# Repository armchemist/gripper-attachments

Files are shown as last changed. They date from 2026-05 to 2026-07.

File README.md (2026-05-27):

# OMX-F 그리퍼 어태치먼트

OMX-F 로봇 팔 그리퍼에 끼워 쓰는 3D 프린팅 부품들 모음이다.

## 파일 구성

```
gripper-attachments/
├── GRIPPER_DIMENSIONS.md       핑거 치수 측정값 정리본
├── analyze_gripper.py          STL에서 단면 치수 뽑는 스크립트
├── gripper_sleeve.scad         범용 슬리브 (파라미터 조절용)
├── omx_f_gripper_sleeve.scad   OMX-F 핑거에 맞게 튜닝된 슬리브
├── omx_f_tube_insert.scad      시험관 잡는 팁 인서트
├── omx_f_tube_insert2~5.scad   튜브 인서트 개선 버전들
└── model/
    └── omx_f_mesh/
        └── follower_07_gripper_motorized.stl   원본 그리퍼 핑거 STL
```

## 새 부품 설계할 때

STL 파일 직접 열어서 치수 잴 필요 없이, `GRIPPER_DIMENSIONS.md`에 블레이드 단면 치수, 피벗 위치, 방향 기준이 다 정리되어 있다. 새 어태치먼트 만들 때는 여기 수치부터 보면 된다.

설계 전에 알아두면 좋은 것:

- **X 0~22 mm** 구간은 모터/기어 하우징이라 건드리면 안 된다
- **X 22~65 mm** 블레이드 구간이 부품 붙이는 영역
- 벽 두께 1.8 mm, 클리어런스 0.3 mm 정도가 FDM 출력 기준점

## OpenSCAD에서 끼움새 확인하는 법

`.scad` 파일 열면 위쪽에 `show_phantom` 파라미터가 있는데, `true`로 바꾸면 핑거 블레이드 형태가 반투명하게 같이 뜬다. 부품이 어디에 걸리는지 대충 보기엔 충분하다.

더 정확하게 원본 메시 위에 얹어서 보고 싶으면 파일 맨 아래에 이거 한 줄 추가하면 된다:

```scad
// 내보내기 전에 꼭 지울 것
%import("model/omx_f_mesh/follower_07_gripper_motorized.stl");
```

`%`를 붙이면 F5 프리뷰에서는 반투명 고스트로 보이고, F6 렌더링이나 STL 내보내기에는 포함이 안 된다. 출력 파일 걱정 없이 끼움새만 눈으로 확인할 수 있다.

## 출력 워크플로우

1. OpenSCAD에서 `.scad` 파일 열기
2. `show_phantom = true` 또는 `%import(...)` 추가하고 **F5**로 끼움새 확인
3. STL 내보낼 때는 다시 `false`로 돌리고 `%import` 줄 지우기
4. **F6** 렌더 → **F7** STL 내보내기
5. 출력 방향: X축이 베드 길이 방향이 되도록 눕혀서
6. 재료: PETG나 TPU 95A 추천, 벽 3~4겹, 인필 20%

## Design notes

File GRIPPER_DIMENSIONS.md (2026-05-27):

# OMX_F gripper finger dimensions

Source: STL analysis of `omx_f_mesh/follower_07_gripper_motorized.stl` (link6) and `follower_08_gripper_gear.stl` (link7), cross-referenced with `omx_f.urdf`. All units mm.

Reference these numbers when designing any gripper attachment (sleeve, jig, sensor mount, swap tool) instead of re-analyzing STLs.

## Mounting (from URDF, relative to link5)
- link6 pivot: xyz = (29.5, 7.5, 0), axis Z, mimic master
- link7 pivot: xyz = (29.5, -10.8, 0), axis Z, mimic of link6 ×(-1)
- Pivot Y spacing: 18.3 mm
- Both fingers symmetric (mirror in Y); link6 has motor housing, link7 has gear.

## Finger geometry (finger-local frame, X = length, pivot at X=0)
Total bbox: ~75 × 20 × ~42 mm (X × Y × Z, watertight).

| Zone | X range (mm) | Y width | Z height | Notes |
|---|---|---|---|---|
| Pivot shaft | -10 to 0 | ~0 (axle) | ~4 | rotation axis (Z) |
| Housing block | 0 to ~22 | ~20 | ~42 | motor/gear body — DO NOT cover |
| Grip blade (taper) | 22 to 65 | 11 → 7 | 39 → 16 | usable for attachments |
| Tip | 65 | <4 | ~15 | flat edge |

### Blade cross-sections (link6, symmetrized half-extents)
Measured via `trimesh.section()` (proper planar cross-section).
| Finger-local X | half_Y | half_Z |
|---|---|---|
| 22 (blade base) | 5.7  | 19.4 |
| 28 | 4.2  | 17.7 |
| 36 | 3.1  | 15.5 |
| 46 | 2.8  | 12.7 |
| 55 | 3.5  | 10.3 |
| 62 | 3.5  | 8.3  |
| 65 (tip) | ~3.0 | ~7.6 |

## Inner / outer face convention
- link6 "inner" (gripping) face = local **−Y** (faces partner finger at link7).
- link7 "inner" face = local **+Y** (mirror of link6).
- Closing direction at zero rotation: along link5's Y axis.

## Joint limits (URDF)
All revolute, effort 1000, velocity 4.8 rad/s, range ±2π:
joint1 (base yaw, Z), joint2/3/4 (pitch, Y), joint5 (roll, X), gripper_joint_1/2 (Z, mimic).

## Related files
- `analyze_gripper.py` — STL analysis script (re-run from this folder)
- `gripper_sleeve.scad` — parameterized slide-on sleeve (covers blade x=22..65)
- `../omx_f.urdf` — robot model
- `../omx_f_mesh/follower_07_*.stl`, `follower_08_*.stl` — finger meshes

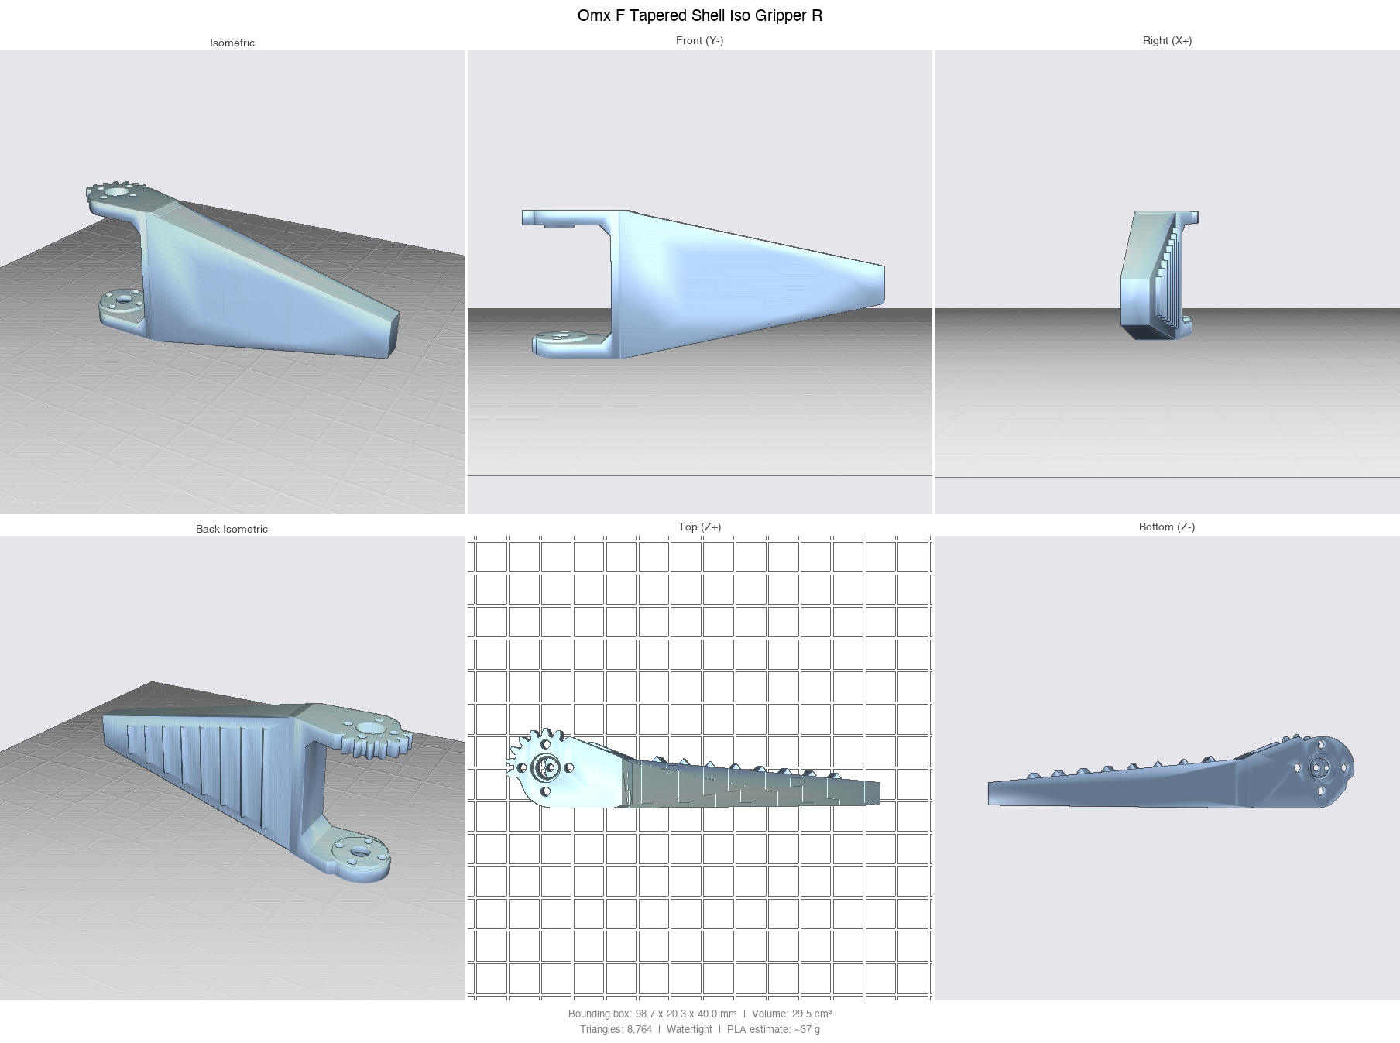
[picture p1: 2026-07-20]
gripper_designs/preview_iso_R.png

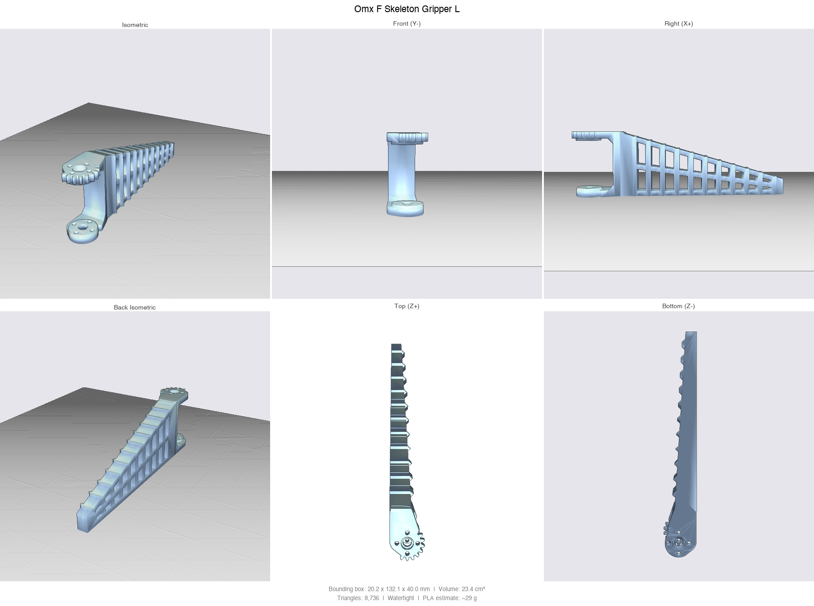
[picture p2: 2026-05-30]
gripper_designs/preview_skeleton.png

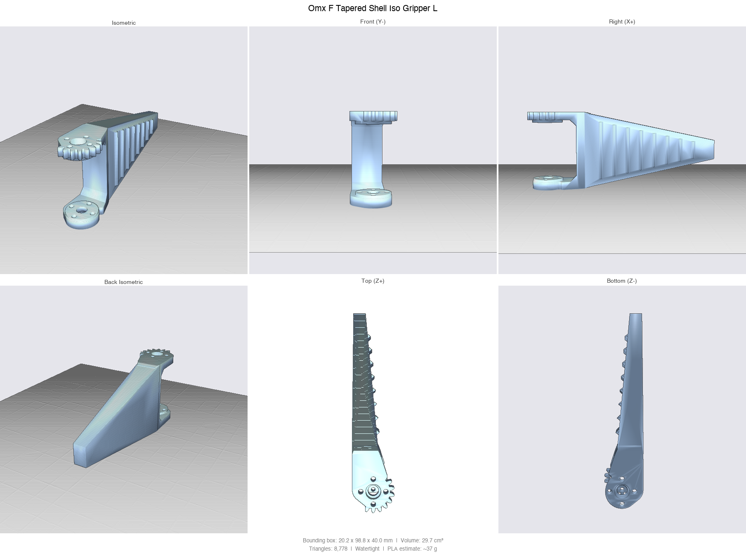
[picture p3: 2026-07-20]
gripper_designs/preview_iso.png

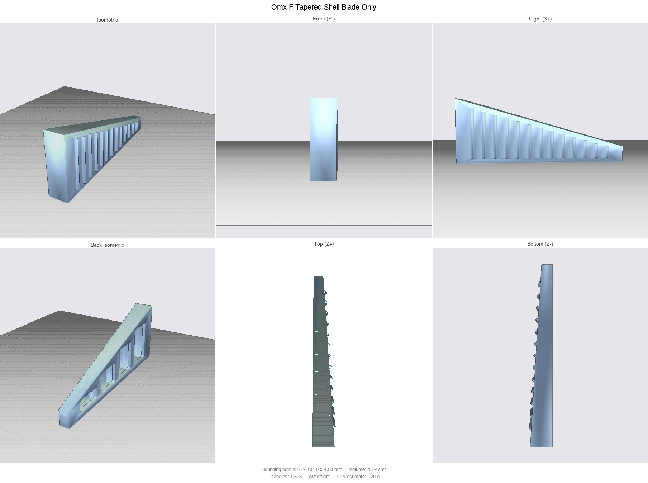
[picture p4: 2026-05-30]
gripper_designs/preview_blade.png

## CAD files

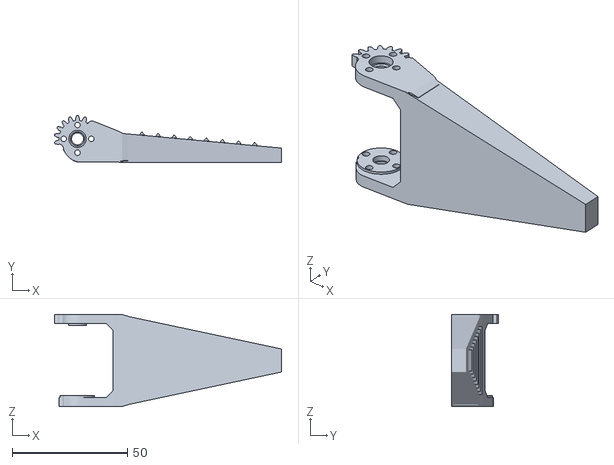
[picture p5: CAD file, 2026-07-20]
gripper_designs/omx_f_tapered_shell_iso_gripper_R.stl
98.7 x 20.3 x 40.0

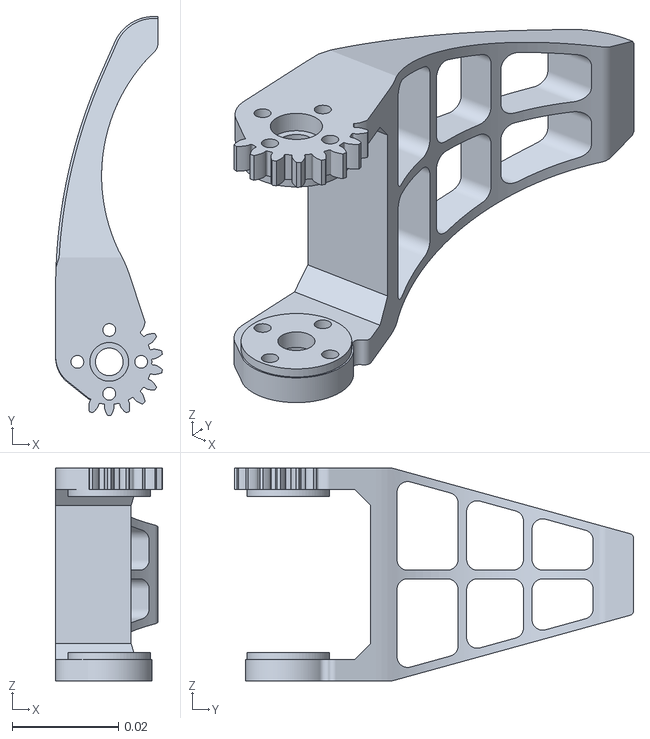
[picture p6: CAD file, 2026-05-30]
model/omx_f_mesh/follower_gripper_l.stl
0.0201 x 0.0751 x 0.04

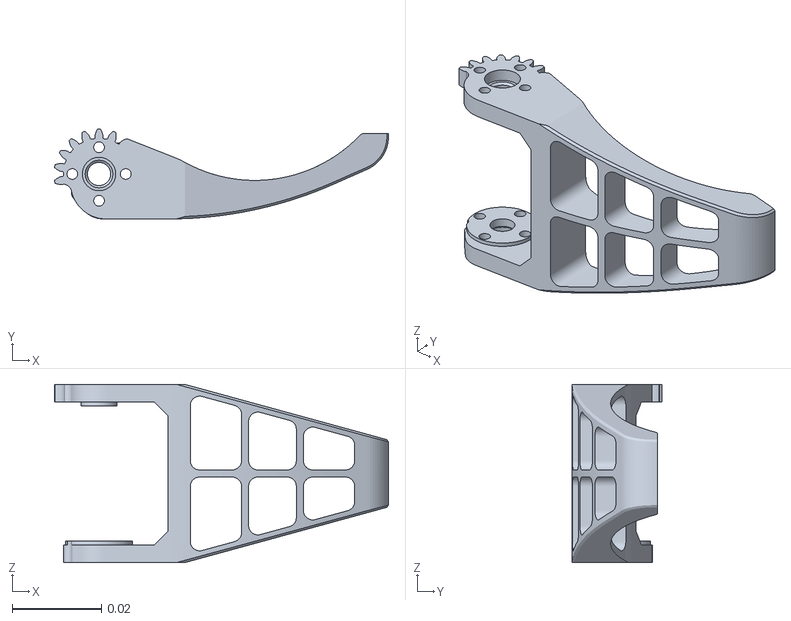
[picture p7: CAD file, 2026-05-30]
model/omx_f_mesh/follower_gripper_r.stl
0.075 x 0.0202 x 0.04

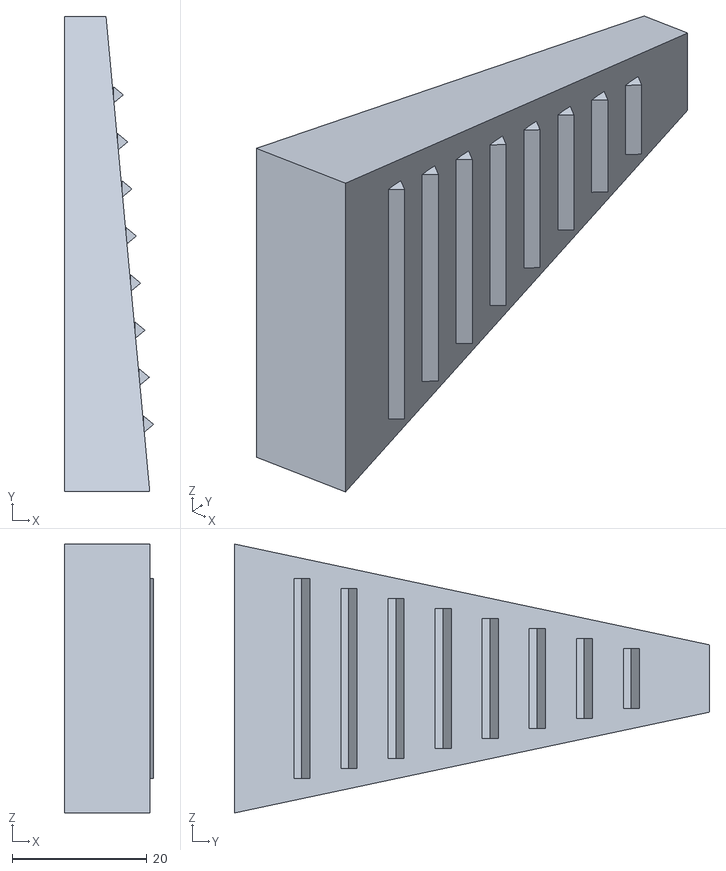
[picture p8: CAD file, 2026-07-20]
gripper_designs/omx_f_tapered_shell_iso_blade_only.stl
13.3 x 70.7 x 40.0

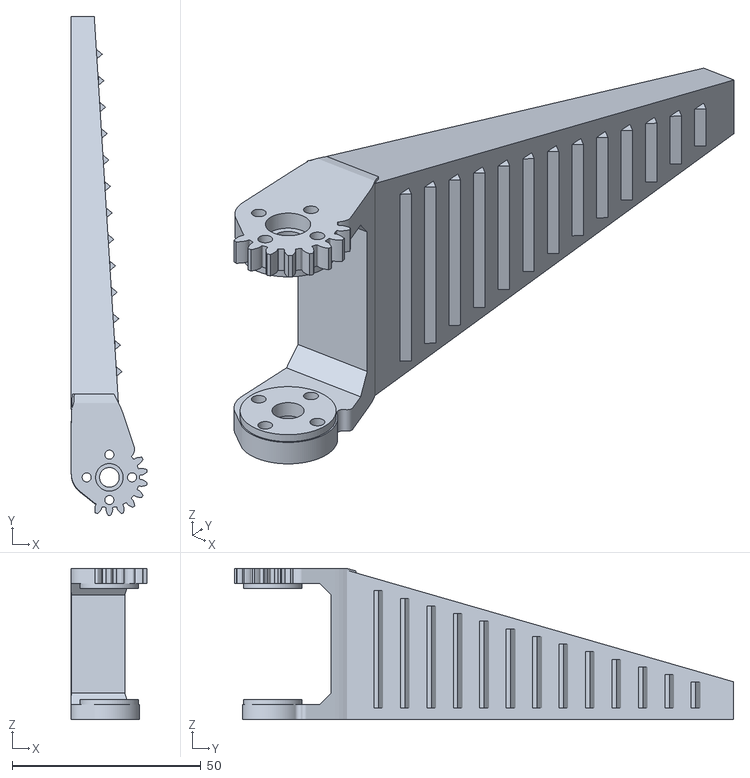
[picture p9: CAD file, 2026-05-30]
gripper_designs/omx_f_tapered_shell_gripper_L.stl
20.2 x 132.1 x 40.0

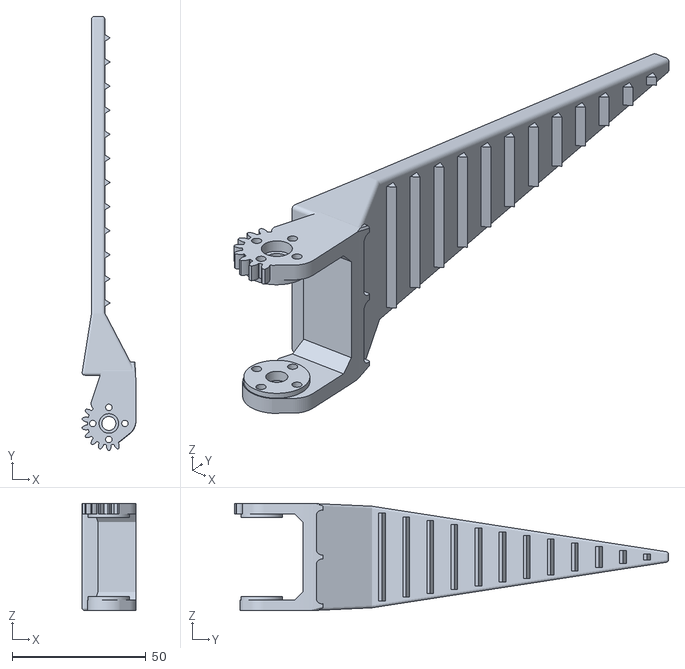
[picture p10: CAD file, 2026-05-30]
gripper_designs/omx_f_flat_tube_gripper_R.stl
20.1 x 162.1 x 40.0

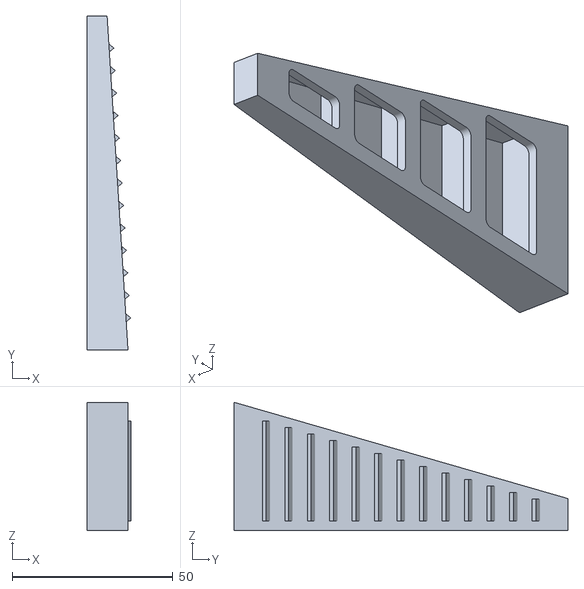
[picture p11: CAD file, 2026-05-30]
gripper_designs/omx_f_tapered_shell_blade_only.stl
13.6 x 104.0 x 40.0

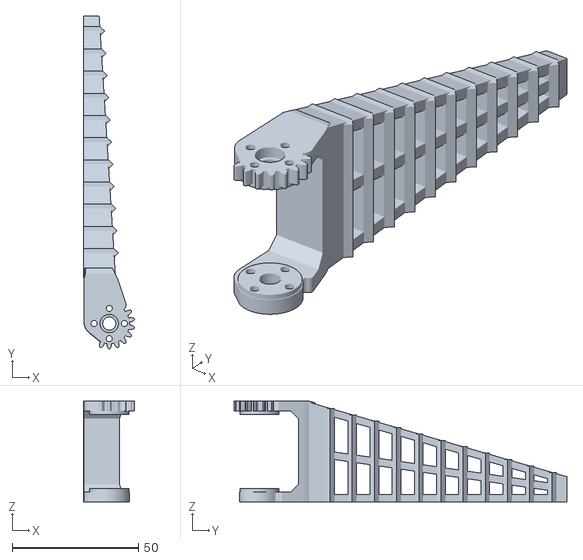
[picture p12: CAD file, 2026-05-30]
gripper_designs/omx_f_skeleton_gripper_L.stl
20.2 x 132.1 x 40.0

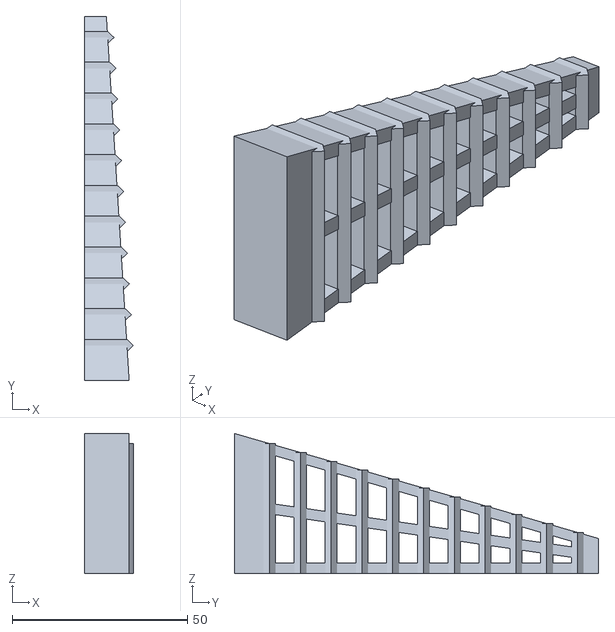
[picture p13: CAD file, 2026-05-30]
gripper_designs/omx_f_skeleton_blade_only.stl
13.9 x 104.0 x 40.0

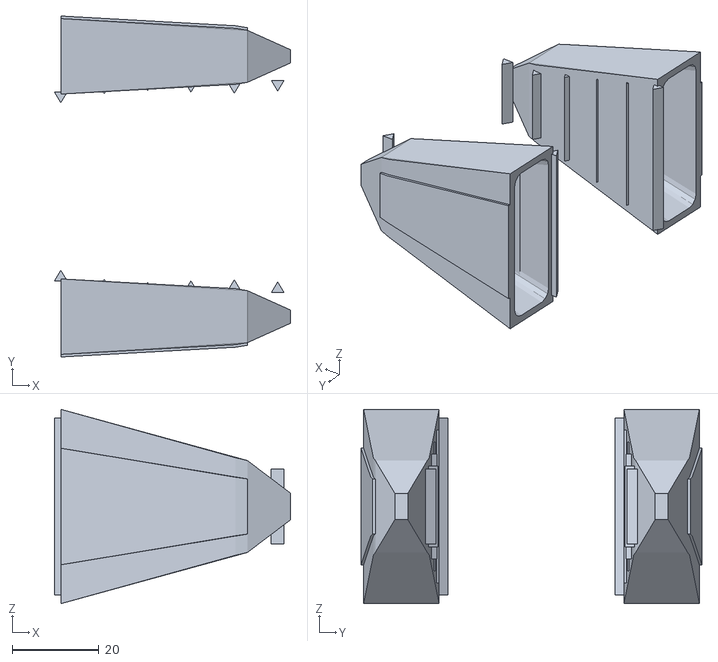
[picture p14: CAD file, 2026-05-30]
gripper_designs/omx_f_long_finger_fit.stl
54.5 x 78.6 x 44.8

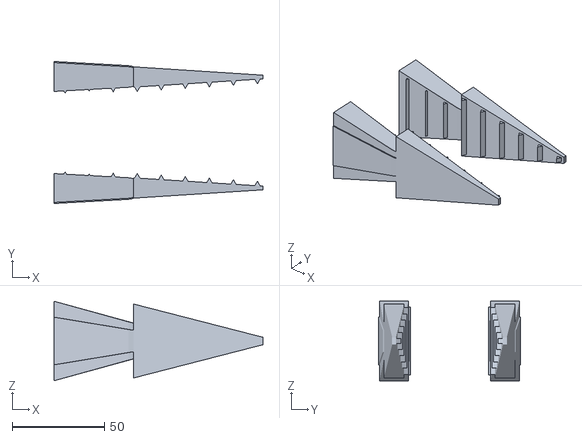
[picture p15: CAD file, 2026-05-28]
gripper_designs/omx_f_long_finger.stl
113.0 x 76.8 x 43.0

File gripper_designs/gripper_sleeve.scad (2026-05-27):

// =====================================================================
//  OMX_F gripper finger sleeve — slide-on cover
//  Fits over the fingertip blade (finger-local x = 22..65 mm).
//  Open end pushes onto the finger from the tip side and slides toward
//  the housing until seated.
//
//  variant : "vgroove" (cradle for cylinders, Φ4..16 mm)
//          : "cup"     (concave dimples for spheres / small parts)
//  mirror_y: false = link6 (motorized side)
//            true  = link7 (gear side)   — mirrored pair
//
//  Print suggestion: PLA/PETG, 0.2 mm layer, 4 walls, 30% infill.
//  Print orientation: lay flat on +Z face (grip pad facing up).
//  If too tight, increase `clearance` by 0.1. If too loose, decrease.
// =====================================================================

variant   = "vgroove";   // "vgroove" | "cup"
mirror_y  = false;

clearance = 0.4;         // gap between sleeve cavity and finger (per side)
wall      = 1.6;         // shell wall thickness
$fn       = 80;

// ---------------------------------------------------------------------
// Blade outer envelope (symmetrized, derived from STL cross-sections
// of follower_07_gripper_motorized.stl over finger-local x = 22..65 mm).
// Format: [x_from_sleeve_base, half_width_Y, half_height_Z]
// ---------------------------------------------------------------------
profile = [
  [ 0.0,  5.7, 19.4],
  [ 6.0,  4.2, 17.7],
  [14.0,  3.1, 15.5],
  [24.0,  2.8, 12.7],
  [33.0,  3.5, 10.3],
  [40.0,  3.5,  8.3],
  [43.0,  3.0,  7.6],
];
N = len(profile);
L = profile[N-1][0];        // total sleeve length along finger axis

// ---------------------------------------------------------------------
// Helpers — tapered solid built by chained hulls of thin slabs
// ---------------------------------------------------------------------
module slab(i, ey, ez) {
  s = profile[i];
  translate([s[0], 0, 0])
    cube([0.02, 2*(s[1]+ey), 2*(s[2]+ez)], center=true);
}
module taper(ey, ez) {
  for (i = [0 : N-2]) hull() { slab(i, ey, ez); slab(i+1, ey, ez); }
}

// ---------------------------------------------------------------------
// Shell = outer taper − inner cavity (cavity opens at x = 0)
// ---------------------------------------------------------------------
module shell() {
  difference() {
    taper(clearance + wall, clearance + wall);
    // base opening: cut through x = 0 face
    translate([-3, 0, 0])
      cube([3.02,
            2*(profile[0][1] + clearance),
            2*(profile[0][2] + clearance)], center=true);
    // inner cavity matching blade with clearance
    taper(clearance, clearance);
  }
}

// ---------------------------------------------------------------------
// Grip pad on −Y face (the "inner" face that meets the partner finger
// for link6; mirrored for link7 via the top-level mirror).
// ---------------------------------------------------------------------
pad_len = 34;
pad_h   = 14;       // Z extent
pad_thk = 4.5;      // protrusion in −Y from outer wall
pad_x0  = 4;

pad_y_attach = -(profile[0][1] + clearance + wall);  // pad's +Y face (into shell)
pad_y_grip   = pad_y_attach - pad_thk;               // pad's −Y face (gripping surface)

module pad_block() {
  // overlap +1 mm into shell so the union is robust
  translate([pad_x0, pad_y_grip, -pad_h/2])
    cube([pad_len, pad_thk + 1.0, pad_h]);
}

// V-groove: triangular notch running along Z, centered along X on the pad.
// Cylinder lies vertically (along Z) and seats in the V.
module v_cutter() {
  groove_w = 9.0;     // width at the grip surface
  groove_d = 2.8;     // depth into pad
  translate([pad_x0 + pad_len/2, pad_y_grip, -pad_h/2 - 2])
    linear_extrude(height = pad_h + 4)
      polygon([
        [-groove_w/2, 0     ],   // left lip on grip surface
        [ groove_w/2, 0     ],   // right lip
        [ 0,          groove_d]  // apex, inward into pad
      ]);
}

// Cup: two hemispherical dimples on grip face for small spheres / parts.
module cup_cutter() {
  r_big   = 4.5;   // ~Φ9 cavity → holds Φ6–10 mm objects
  r_small = 3.0;   // ~Φ6 cavity → holds Φ3–6 mm objects
  // sphere center sits ON the grip surface → cuts a hemisphere into the pad
  translate([pad_x0 + 11, pad_y_grip, 0]) sphere(r = r_big);
  translate([pad_x0 + 24, pad_y_grip, 0]) sphere(r = r_small);
}

// ---------------------------------------------------------------------
// Assembly
// ---------------------------------------------------------------------
module sleeve() {
  difference() {
    union() {
      shell();
      pad_block();
    }
    if (variant == "vgroove") v_cutter();
    else if (variant == "cup") cup_cutter();
  }
}

// Mirror for link7 if requested
if (mirror_y) mirror([0, 1, 0]) sleeve();
else sleeve();

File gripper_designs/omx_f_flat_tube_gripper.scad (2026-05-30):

// ============================================================
//  OMX_F Flat Tube Gripper — Direct Motor-Mount Replacement
//  ─────────────────────────────────────────────────────────
//  follower_gripper_l.stl 의 모터 마운트/하우징부 (y = 0..cut_y) 만 그대로
//  살리고, 그 너머의 블레이드를 평평한 긴 핑거로 교체.
//  안쪽 면 (-X) 에 세로 리지를 일정 간격 배치 → 15 mL 팔콘 (Φ~17 mm)
//  같은 시험관을 미끄러짐 없이 잡도록 설계.
//
//  좌표계 (L STL 원본 그대로):
//    Y = 핑거 길이축 (모터에서 바깥)
//    Z = 세로 높이
//    X = 두께 / 그립 방향 (-X 가 짝 핑거 방향 = 안쪽)
//
//  L 버전: which_side = "L"
//  R 버전: which_side = "R"  → X 미러 (짝 핑거)
// ============================================================

// ── USER PARAMETERS ─────────────────────────────────────────

// 어디서 원본을 자를지 (mm, Y 축). 22 = 하우징 끝.
// 더 크게 = 원본 블레이드 더 많이 남김 (보강)
// 더 작게 = 더 빨리 새 블레이드로 전환
cut_y           = 23.0;

// 새 블레이드 (이등변 삼각형 측면 프로파일 — 베이스 wide, 팁 sharp point)
// 두께(X) 는 일정, 높이(Z) 만 베이스→팁 으로 균등 수축 (상하 동시 좁힘)
blade_length    = 110.0;   // cut_y 부터 새 블레이드 끝까지 길이 (mm)
blade_thick     = 5.0;     // X 두께 (mm) — 베이스/팁 일정
blade_base_height = 38.0;  // 베이스 Z 세로 높이 (mm) — 하우징 크기와 비슷
blade_tip_height  = 4.0;   // 팁 Z 세로 높이 (mm) — 뾰족
blade_x_center  = 4.0;     // 블레이드 중심 X 좌표 (원본 블레이드 위치와 일치)
blade_z_center  = -16.0;   // 블레이드 중심 Z 좌표 (원본 블레이드 중심)
blade_corner_r  = 1.0;     // 블레이드 코너 라운딩 (mm)

// 베이스 접합 보강 — 모터 하우징과 블레이드 사이를 두꺼운 넥(neck)으로 연결
// 넥 베이스(하우징 쪽)는 하우징 외형 (X=-10..10, Z=-36..4) 을 그대로 덮어
// 단차 없이 매끈하게 이어지도록 한다.
joint_length_y  = 18.0;    // 접합 넥 Y 길이 (mm)
joint_overlap_y = 4.0;     // 넥이 하우징 안으로 파고드는 깊이 (mm) — 강한 union
joint_base_xmin = -10.0;   // 넥 베이스 X 최소 (하우징 외형과 일치)
joint_base_xmax =  10.0;   // 넥 베이스 X 최대
joint_base_zmin = -36.0;   // 넥 베이스 Z 최소 (하우징 외형과 일치)
joint_base_zmax =   4.0;   // 넥 베이스 Z 최대

// 그립 리지 (안쪽 면 = -X 방향 돌출)
ridge_pitch     = 9.0;     // 리지 Y 방향 간격 (mm)
ridge_width     = 3.0;     // 리지 베이스 Y 폭 (mm)
ridge_height    = 2.0;     // 리지 -X 방향 돌출 깊이 (mm)
ridge_z_margin  = 2.0;     // 리지가 블레이드 Z 가장자리에서 떨어지는 거리 (mm)
ridge_start_y   = 45.0;    // 첫 리지 Y 위치 (mm) — 두꺼운 넥 끝나는 지점부터

// 출력 / 미리보기
which_side      = "L";     // "L" | "R" | "both"
show_phantom    = true;    // 원본 STL 반투명 표시 (STL export 전엔 false)

// ── DERIVED ─────────────────────────────────────────────────
STL_L = "../model/omx_f_mesh/follower_gripper_l.stl";
STL_R = "../model/omx_f_mesh/follower_gripper_r.stl";

// 원본 STL 은 미터 단위. OpenSCAD 에서 mm 로 다루려면 1000 배 스케일.
STL_SCALE = 1000;

EPS = 0.01;
$fn = 32;

// Y 좌표
// 넥은 하우징 안쪽으로 joint_overlap_y 만큼 파고들어 union 강도 확보
joint_y_start = cut_y - joint_overlap_y;
joint_y_end   = cut_y + joint_length_y;
blade_y_start = joint_y_end;
blade_y_end   = blade_y_start + blade_length;

// 임의 Y 에서의 블레이드 단면 (linear interp, t=0 at base, t=1 at tip)
function blade_t(y) = max(0, min(1, (y - blade_y_start)/blade_length));
function blade_height_at(y) = blade_base_height + (blade_tip_height - blade_base_height)*blade_t(y);

// 두께는 일정 — 안쪽 면 X 좌표 고정
blade_inner_x = blade_x_center - blade_thick/2;
blade_outer_x = blade_x_center + blade_thick/2;

// ── MODULES ─────────────────────────────────────────────────

// 원본 STL 에서 y >= cut_y 부분을 잘라낸 마운트
module mount_l() {
    difference() {
        scale([STL_SCALE, STL_SCALE, STL_SCALE])
            import(STL_L, convexity = 10);
        // 큰 박스로 y >= cut_y 영역 모두 제거
        translate([-100, cut_y, -100])
            cube([200, 200, 200]);
    }
}

// 테이퍼 블레이드 — 이등변 형태로 베이스 → 팁 hull
// 안쪽 (-X) / 바깥 (+X) / 위 (+Z) / 아래 (-Z) 모두 중심으로 균등 수축
module tapered_blade() {
    r = blade_corner_r;
    // 베이스 (Y = blade_y_start): X 두께 = blade_thick, Z = blade_base_height
    base_z_min = blade_z_center - blade_base_height/2;
    base_z_max = blade_z_center + blade_base_height/2;
    // 팁 (Y = blade_y_end): X 두께 동일, Z = blade_tip_height (이등변 상하 대칭 수축)
    tip_z_min  = blade_z_center - blade_tip_height/2;
    tip_z_max  = blade_z_center + blade_tip_height/2;

    hull() {
        for (x = [blade_inner_x + r, blade_outer_x - r])
        for (z = [base_z_min + r, base_z_max - r])
            translate([x, blade_y_start, z]) sphere(r = r);
        for (x = [blade_inner_x + r, blade_outer_x - r])
        for (z = [tip_z_min + r, tip_z_max - r])
            translate([x, blade_y_end, z]) sphere(r = r);
    }
}

// 두꺼운 넥 — 하우징과 블레이드 사이 굵은 연결부
// 하우징 쪽 단면 (Y = cut_y) 은 하우징 크기에 맞춰 큼직하게,
// 블레이드 베이스 쪽 단면 (Y = joint_y_end) 은 블레이드 베이스와 일치
module thick_neck() {
    r = blade_corner_r;
    // 하우징 쪽 단면 (Y = joint_y_start) — 하우징 외형 그대로 (-10..10, -36..4)
    // 블레이드 베이스 쪽 단면 (Y = joint_y_end) — 블레이드 베이스와 매칭
    base_x_min = blade_inner_x;
    base_x_max = blade_outer_x;
    base_z_min = blade_z_center - blade_base_height/2;
    base_z_max = blade_z_center + blade_base_height/2;

    hull() {
        // 하우징 매칭 단면 (Y=joint_y_start, 하우징 내부로 살짝 파고듬)
        for (x = [joint_base_xmin + r, joint_base_xmax - r])
        for (z = [joint_base_zmin + r, joint_base_zmax - r])
            translate([x, joint_y_start, z]) sphere(r = r);
        // 블레이드 베이스 단면 (Y=joint_y_end)
        for (x = [base_x_min + r, base_x_max - r])
        for (z = [base_z_min + r, base_z_max - r])
            translate([x, joint_y_end, z]) sphere(r = r);
    }
}

// 단일 리지 (Y = y_pos 위치, 안쪽 -X 면에서 돌출)
// 안쪽 면이 이등변 테이퍼라 Y 마다 위치/높이 달라짐 → 함수로 계산
module ridge_at(y_pos) {
    local_h = blade_height_at(y_pos);
    tooth_h = max(2.0, local_h - 2*ridge_z_margin);
    base_x  = blade_inner_x + 0.4;
    peak_x  = blade_inner_x - ridge_height;
    translate([0, y_pos, blade_z_center])
    linear_extrude(height = tooth_h, center = true)
        polygon([
            [base_x, -ridge_width/2],
            [peak_x, 0],
            [base_x,  ridge_width/2],
        ]);
}

module all_ridges() {
    n = floor((blade_y_end - blade_corner_r - ridge_start_y) / ridge_pitch);
    for (i = [0 : n]) {
        y = ridge_start_y + i * ridge_pitch;
        if (y + ridge_width/2 < blade_y_end - blade_corner_r)
            ridge_at(y);
    }
}

// 완성된 L 핑거 = 잘라낸 마운트 + 두꺼운 넥 + 테이퍼 블레이드 + 리지
module finger_l() {
    union() {
        mount_l();
        thick_neck();
        tapered_blade();
        all_ridges();
    }
}

// R = L 의 X-미러 (그립 방향이 +X 가 됨)
module finger_r() {
    mirror([1, 0, 0]) finger_l();
}

// 원본 STL 팬텀 (정렬 확인)
module phantom_l() { color("cyan", 0.25) scale([STL_SCALE, STL_SCALE, STL_SCALE]) import(STL_L, convexity = 10); }
module phantom_r() { color("cyan", 0.25) scale([STL_SCALE, STL_SCALE, STL_SCALE]) import(STL_R, convexity = 10); }

// ── RENDER ──────────────────────────────────────────────────
SEP_X = 50;  // both 모드 시각 분리

if (which_side == "L") {
    finger_l();
    if (show_phantom) phantom_l();
} else if (which_side == "R") {
    finger_r();
    if (show_phantom) phantom_r();
} else {  // both
    translate([-SEP_X/2, 0, 0]) {
        finger_l();
        if (show_phantom) phantom_l();
    }
    translate([ SEP_X/2, 0, 0]) {
        finger_r();
        if (show_phantom) phantom_r();
    }
}

// ============================================================
//  출력 가이드
//  ─────────────────────────────────────────────────────────
//  재료     : PETG 권장 (강성 + 약간의 탄성). PLA 가능.
//  방향     : 블레이드 평평한 바깥면 (+X 면) 을 베드에 깔고 출력
//             → 리지가 위로, 서포트 없이 모든 면 클린
//             OpenSCAD 에서 export 전 rotate([0, -90, 0]) 권장
//  레이어   : 0.2 mm
//  벽       : 3-4 perimeters, 인필 20-25 %
//
//  STL 내보내기 전
//  ─────────────────────────────────────────────────────────
//  1. show_phantom = false
//  2. which_side  = "L" 또는 "R"
//  3. F6 렌더 (원본 STL 부울 때문에 수십 초 걸릴 수 있음)
//  4. F7 STL export
// ============================================================

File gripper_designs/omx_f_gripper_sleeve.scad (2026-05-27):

// ============================================================
//  OMX_F Gripper Finger Sleeve
//  Fits link6 (motorized) AND link7 (gear) — blade zone only
//  Blade X range: 22 mm → 65 mm  (finger-local frame)
//  Source dimensions: OMX_F gripper finger spec sheet
// ============================================================

// ── USER PARAMETERS ─────────────────────────────────────────

// Wall thickness around the blade (mm)
wall = 1.8;

// Extra clearance added to every cross-section (mm, tweak for print fit)
clearance = 0.3;

// Grip surface texture: "smooth", "ridged", "dotted"
grip_texture = "ridged";

// Ridged texture settings (ignored if grip_texture != "ridged")
ridge_pitch = 4.0;   // spacing between ridges (mm)
ridge_depth = 0.6;   // depth of each ridge (mm)

// Show the finger phantom (for visual check — disable before exporting)
show_phantom = false;

// Which finger to generate: "link6", "link7", or "both"
finger = "both";

// ── BLADE CROSS-SECTION DATA (from spec sheet) ───────────────
//   [ X,  half_Y, half_Z ]  — all mm, finger-local frame
blade_pts = [
    [ 22,  5.7, 19.4 ],
    [ 28,  4.2, 17.7 ],
    [ 36,  3.1, 15.5 ],
    [ 46,  2.8, 12.7 ],
    [ 55,  3.5, 10.3 ],
    [ 62,  3.5,  8.3 ],
    [ 65,  3.0,  7.6 ],
];

// ── DERIVED VALUES ────────────────────────────────────────────
sleeve_x_start = blade_pts[0][0];          // 22
sleeve_x_end   = blade_pts[len(blade_pts)-1][0];  // 65
sleeve_length  = sleeve_x_end - sleeve_x_start;   // 43

// ── HELPERS ───────────────────────────────────────────────────

// Linearly interpolate blade cross-section at a given X position
function blade_half_y(x) =
    let(i = search_segment(x))
    let(x0 = blade_pts[i][0],   y0 = blade_pts[i][1],
        x1 = blade_pts[i+1][0], y1 = blade_pts[i+1][1])
    y0 + (y1-y0) * (x-x0)/(x1-x0);

function blade_half_z(x) =
    let(i = search_segment(x))
    let(x0 = blade_pts[i][0],   z0 = blade_pts[i][2],
        x1 = blade_pts[i+1][0], z1 = blade_pts[i+1][2])
    z0 + (z1-z0) * (x-x0)/(x1-x0);

// Return the blade_pts index i such that blade_pts[i][0] <= x < blade_pts[i+1][0]
function search_segment(x, i=0) =
    (i >= len(blade_pts)-2) ? i :
    (x <= blade_pts[i+1][0]) ? i : search_segment(x, i+1);

// ── SLEEVE BODY ───────────────────────────────────────────────
// Built as a hull of scaled rectangles along X, then subtract the
// inner cavity (blade shape + clearance).

N_SLICES = 20;   // number of cross-section slices

module blade_slice(x, extra_y=0, extra_z=0) {
    hy = blade_half_y(x) + extra_y;
    hz = blade_half_z(x) + extra_z;
    translate([x, 0, 0])
        cube([0.01, hy*2, hz*2], center=true);
}

module sleeve_outer() {
    hull()
        for (i = [0:N_SLICES]) {
            x = sleeve_x_start + i * sleeve_length / N_SLICES;
            blade_slice(x, extra_y = wall + clearance,
                           extra_z = wall + clearance);
        }
}

module sleeve_inner_cavity() {
    // finger blade + clearance gap
    hull()
        for (i = [0:N_SLICES]) {
            x = sleeve_x_start + i * sleeve_length / N_SLICES;
            blade_slice(x, extra_y = clearance,
                           extra_z = clearance);
        }
}

// Entry chamfer — open the back end so the blade slides in easily
module entry_chamfer() {
    chamfer = 3.0;
    hull() {
        blade_slice(sleeve_x_start,
            extra_y = clearance + wall,
            extra_z = clearance + wall);
        blade_slice(sleeve_x_start,
            extra_y = clearance + wall + chamfer,
            extra_z = clearance + wall + chamfer);
        translate([sleeve_x_start - chamfer, 0, 0])
            blade_slice(sleeve_x_start,
                extra_y = clearance + wall + chamfer,
                extra_z = clearance + wall + chamfer);
    }
}

// Ridged grip texture on the outer −Y face (inner/gripping side)
module add_ridges() {
    n_ridges = floor(sleeve_length / ridge_pitch);
    for (i = [0:n_ridges-1]) {
        x = sleeve_x_start + (i + 0.5) * ridge_pitch;
        if (x < sleeve_x_end) {
            hy_out = blade_half_y(x) + wall + clearance;
            hz_out = blade_half_z(x) + wall + clearance;
            // Ridge sits on the −Y (inner/gripping) face
            translate([x, -hy_out, 0])
                rotate([0, 90, 0])
                    cylinder(d=ridge_depth*2, h=1.0, center=true, $fn=8);
        }
    }
}

// Full sleeve for one finger
module sleeve(mirror_y=false) {
    scale([1, mirror_y ? -1 : 1, 1])
    difference() {
        union() {
            sleeve_outer();
            if (grip_texture == "ridged") add_ridges();
        }
        sleeve_inner_cavity();
        entry_chamfer();
    }
}

// ── PHANTOM FINGER (visual check only) ───────────────────────
module finger_phantom() {
    color("cyan", 0.25)
    hull()
        for (i = [0:N_SLICES]) {
            x = sleeve_x_start + i * sleeve_length / N_SLICES;
            blade_slice(x);
        }
}

// ── RENDER ───────────────────────────────────────────────────
// link6: inner face = −Y  (no Y mirror needed)
// link7: inner face = +Y  (mirror in Y)

Y_OFFSET = 22;   // visual separation when showing both

if (finger == "link6") {
    sleeve(mirror_y=false);
    if (show_phantom) finger_phantom();

} else if (finger == "link7") {
    sleeve(mirror_y=true);
    if (show_phantom) finger_phantom();

} else { // "both" — side by side
    translate([0,  Y_OFFSET, 0]) {
        sleeve(mirror_y=false);
        if (show_phantom) finger_phantom();
    }
    translate([0, -Y_OFFSET, 0]) {
        sleeve(mirror_y=true);
        if (show_phantom) finger_phantom();
    }
}

// ============================================================
// USAGE NOTES
// ─────────────────────────────────────────────────────────────
// 1. Open in OpenSCAD ≥ 2021.01
// 2. Set `show_phantom = false` before exporting STL
// 3. Render (F6) → Export as STL (F7)
// 4. Print orientation: lay flat (X axis = print bed length)
// 5. Recommended: PETG or TPU for grip; 3–4 walls, 20 % infill
// 6. If sleeve is loose, increase `wall`; if too tight, increase `clearance`
// 7. Inner/outer face convention:
//      link6 "inner" (gripping) = local −Y  → sleeve open on −Y side
//      link7 "inner" (gripping) = local +Y  → mirrored
// ============================================================

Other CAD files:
gripper_designs/omx_f_tapered_shell_iso_gripper_L.stl
gripper_designs/omx_f_flat_tube_gripper_L.stl
gripper_designs/omx_f_long_finger.scad
gripper_designs/omx_f_long_finger_fit.scad
gripper_designs/omx_f_tube_insert.scad
gripper_designs/omx_f_tube_insert2.scad
gripper_designs/omx_f_tube_insert3.scad
gripper_designs/omx_f_tube_insert4.scad
gripper_designs/omx_f_tube_insert5.scad

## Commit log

2026-05-27 Initial commit: OMX-F gripper attachments
    OpenSCAD designs and dimension reference for 3D-printed gripper sleeves
    and tube inserts for the OMX-F robot arm.
    [gripper_sleeve.scad, omx_f_gripper_sleeve.scad, omx_f_tube_insert.scad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]
2026-05-27 Add README and .gitignore
    README covers design workflow with GRIPPER_DIMENSIONS.md reference,
    show_phantom usage, and %import trick for exact mesh fit check in OpenSCAD.
2026-05-27 Add original mesh for checking linkage
    [follower_07_gripper_motorized.stl]
2026-05-27 Add OMX_F Gripper Long Blade Finger Extension model
    [omx_f_long_finger.scad]
2026-05-28 Add stl file for long finger
    [omx_f_long_finger.stl]
2026-05-28 Add left gripper mesh
    [follower_08_gripper_gear.stl]
2026-05-28 Change Length
    [omx_f_long_finger_fit.scad, omx_f_long_finger_fit.stl]
2026-05-30 Add 3d printable model .stl
    [follower_07_gripper_motorized.stl, follower_08_gripper_gear.stl, follower_gripper_l.stl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]
2026-05-30 Add more designs
    [omx_f_flat_tube_gripper.scad, omx_f_flat_tube_gripper_L.stl, omx_f_flat_tube_gripper_R.stl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]
2026-05-30 Add right gripper
    [omx_f_tapered_shell_iso_blade_only.stl, omx_f_tapered_shell_iso_gripper_L.stl, omx_f_tapered_shell_iso_gripper_R.stl]
2026-07-20 블레이드 길이 줄임
    [omx_f_tapered_shell_iso_blade_only.stl, omx_f_tapered_shell_iso_gripper_L.stl, omx_f_tapered_shell_iso_gripper_R.stl]
